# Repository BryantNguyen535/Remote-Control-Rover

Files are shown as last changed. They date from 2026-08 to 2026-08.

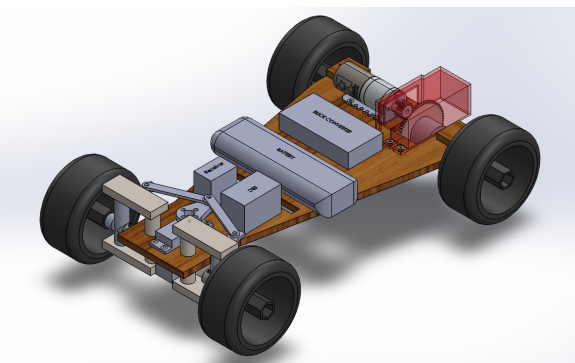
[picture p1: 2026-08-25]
Images/FinalAssembly.png

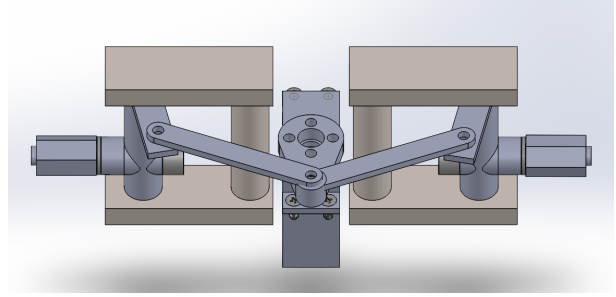
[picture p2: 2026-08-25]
Images/SteeringMechanism.png

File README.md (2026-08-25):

# Team Mott's RC Rover

A custom-designed remote-controlled rover built for **ENGR 7A: Introduction to Engineering** at the **University of California, Irvine (Fall 2023)**[cite: 2].

## System Overview

The Team Mott's Rover is an engineering prototype designed to traverse obstacles, navigate speed courses, and scale steep ramps[cite: 2]. The design features a custom Ackerman steering mechanism, high-torque gearing, custom wood chassis fabrication, and integrated safety covers[cite: 2].

## Key Specifications

| Specification | Value | Target Constraint |
| :--- | :--- | :--- |
| **Dimensions** | 13.94" L x 9.43" W[cite: 2] | < 16.0" L x 10.0" W[cite: 2] |
| **Vehicle Weight** | 1.20 kg[cite: 2] | Predicted: 1.39 kg[cite: 2] |
| **Total Build Cost** | $253.13 (incl. tax)[cite: 2] | < $275.00 limit[cite: 2] |
| **Power Source** | 7.2V 3600 mAh NiMH Battery[cite: 2] | ≥ 10 min operation[cite: 2] |
| **Drive Gear Ratio** | 4:1 (64T Spur / 16T Pinion)[cite: 2] | High-torque selection[cite: 2] |

---

## Subsystem Architecture

### Mechanical & Structural
* **Chassis:** Laser-cut 1/4" Baltic birch plywood featuring custom cutouts for central battery positioning and gear clearance[cite: 2].
* **Ackerman Steering:** Driven by a servo motor attached to a custom 3D-printed adapter horn that connects via rotating linkages to 2-inch D-shaft wheel pivots[cite: 2].
* **Drivetrain:** Features a 12V 4.4:1 metal gearmotor connected via a 64T spur gear to an 8-inch stainless steel rear D-shaft axle[cite: 2].
* **Wheels:** 85 mm rubber tires to maximize ground clearance over course obstacles[cite: 2].
* **Safety Integration:** Includes a transparent 3D-printed red gear guard covering moving drive teeth[cite: 2].

### Electrical & Controls
* **Power Distribution:** 7.2V 3600 mAh NiMH battery feeds directly to the Electronic Speed Controller (ESC) and Buck Converter[cite: 2].
* **Voltage Regulator:** 5A DC-DC Buck Converter steps down 7.2V input to a constant 5V output for the steering servo motor[cite: 2].
* **Radio Control:** 6-channel digital radio transmitter paired with a chassis-mounted receiver[cite: 2].

---

## Competition Performance

* **Preliminary Round:** Completed course in 26.75 seconds, ranking **8th out of 56 teams**[cite: 2].
* **Final Competition (Top 10):** Recorded a 36.00-second course run (+10s penalty for cone contact), securing **6th place overall**[cite: 2].

---

## Future Design Improvements

* **Steering Stabilization:** Replace glued joints with threaded M3 screw connections and shorten sleeve bearing hole depths to eliminate wheel wobble[cite: 2].
* **Friction Reduction:** Convert internal PLA-on-PLA linkage joints to M3 screw pivots[cite: 2].
* **Chassis Clearance:** Shorten overall chassis length or lower axle mount positions to clear ramp peaks without touching[cite: 2].

---

## Team Members

* **Alex M.** — Team Captain[cite: 2]
* **Brady C.** — Electronics Lead[cite: 2]
* **Bryant N.** — CAD Design Lead[cite: 2]
* **Christine R.** — Fabrication Lead[cite: 2]
* **Christine Y.** — Fabrication Lead[cite: 2]
* **Darcy M.** — Research Lead[cite: 2]
* **Emely B.** — Research Lead[cite: 2]

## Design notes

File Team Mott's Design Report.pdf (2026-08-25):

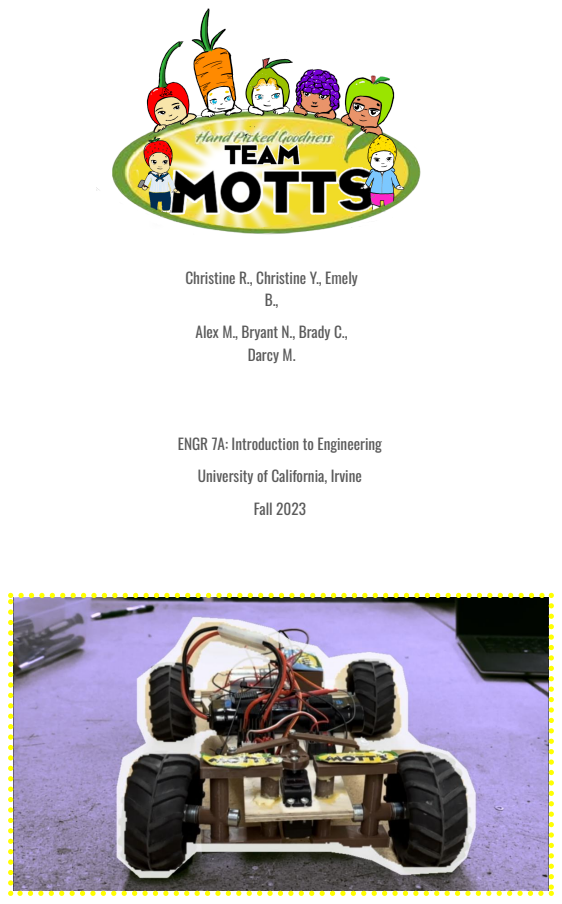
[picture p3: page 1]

Christine R., Christine Y., Emely

Alex M., Bryant N., Brady C.,
Darcy M.

ENGR 7A: Introduction to Engineering
University of California, Irvine
Fall 2023

## Table of Contents

# Executive Summary

ENGR 7A is the first portion of the two-quarter Introduction to Engineering course offered to UCI engineering Freshman. The main objective of this course is to teach its students the various processes and disciplines related to creating a remote control rover. Early on, the students were divided into various groups. Our group consisted of 7 individuals, all of different majors. We early on declared ourselves “Team Motts” when a group member decided to snack on the brand gummies during our first meeting. Few of us had experience with research design and manufacturing and even fewer had experience with electronics. As the course progressed, we would find ourselves dedicating much time building on these skills.
The project began with applying what we learned in lectures and labs onto our weekly action plans. Starting with the 3D CAD design modeling of the rover and its components on SolidWorks. Estimating our costs and collecting the information for the PO form. Then onto the safety protocols and procedures that go into the physical fabrication of the chassis and other smaller wooden parts. The soldering and positioning of the electronics soon followed. Lastly was the testing and evaluation of the end product. As a group, we met every Thursday from 2pm to 3 pm. Our assigned roles directed each of our contributions during and outside the meeting times.
Of course, throughout this whole process, there were many revisions and adjustments done to address issues we faced along the way.
Some of the issues included:
- Fabrication difficulties in original chassis design and steering design
- No space for wheel and motor compartments
- No way to mount rack
- Excessive friction

These issues were solved during labs and weekly meetings. New designs were made for the chassis and steering mechanisms, and different approaches were sought for any issues regarding positioning. Re-printing was also done for 3D components that were misprinted or had gone through revisions in order to fit into new designs.
For the most part, our rover took inspiration from the mechanisms of past accomplished rovers in the same course. Uniquely, our rover also took influence from the mechanisms of remote control toy cars.

Notably, the Ackerman steering system we used was quite different from most other teams as it incorporated rods and a 3D servo motor adapter.
Each member contributed their strengths towards the completion of a rover that not only followed the guidelines set upon us, but also exemplified the creativity of its members. The end product accomplished just that. The Team Mott’s rover is able to remotely be controlled to accelerate, reverse, turn, and climb over a ramp, all while proudly flaunting the Motts brand.

# Problem Definition

Introduction

Over the course of ten weeks, we were tasked with the assignment of fabricating a remotely controlled rover. Going into this project, we had general ideas of aspects desired in our rover such as a low center of gravity, speed, and high torque. Our holistic view of the rover developed as the weeks progressed. We were able to implement what we learned through labs and lectures into our designs, such as ackerman steering and a gear train. Designing and constructing a rover was something novel to the entire team, so the development of the rover was a learning process as well .

Technical Review / Background

The purpose of the rover was to traverse celestial bodies neighboring Earth, and to collect data and samples. In 1970, the Soviet Union developed the first ever rover which was designated the name Lunokhod 1. However, one the earliest records of a remotely controlled vehicle comes from a 1954 article, about a man by the name of David Swinder, which showcases his remote controlled vehicle to the chief test driver of Ford. Rovers have come a long way from Lunokhod 1, with many having developed more specific tasks than just to curiously explore extraterrestrial planes. For example, the most recent rover launched was ‘Perseverance’ by NASA is currently journeying across Mars to look for “signs of past life”, as well as for the ability for humans to live on Mars.
In total transparency, our designs were primarily influenced by what we learned in lab and lecture, but cemented through further research. Designs such as the ackerman steering, gear ratio, materials and center of mass were instructed to us in lecture, which were implemented into our rover as a result.

Resources:

Howell, E. (2016, December 20). Lunokhod 1: 1st successful Lunar Rover. Space.com. https://www.space.com/35090-lunokhod-1.html

RCModels 1954 Ford Motor Company Concept. Thirteen point seven billion. (n.d.). https://palmeter.com/rcmodels-1954-ford-motor-company-concept/

Urbain, T. (2023, May 14). How many Rovers & Landers are currently on Mars?. StarLust. https://starlust.org/how-many-rovers-are-on-mars/

What makes a Rover? - chabot space and science center. (n.d.). https://chabotspace.org/wp-content/uploads/2020/04/What-Makes-a-Rover-1.pdf Design Requirements

Size requirements:
(a) Overall width must be smaller than 10 inches.
(b) Overall length must be smaller than 16 inches.

Structure requirements
(a) Your team will design and fabricate the rover structure.
(b) Using an off the shelf chassis is not allowed.
(c) Off the shelf steering mechanisms or individual linkage components are not allowed.
(d) You are allowed to use raw materials purchased externally with the permission of your TA or technical staff.
(e) 3D printing of the steering mechanism and any associated attachments is allowed, but must be counted toward your budget.

Power and propulsion requirements
(a) The use of internal combustion engines (gas and glow fuel engines) is prohibited.
(b) Rover must be able to operate for at least 10 minutes without replenishing/recharging its energy source.
(c) On/off switch is required and must be easily accessible.
(d) Battery must be easily removable.

Safety requirements
(a) Must include a gear guard to protect against any contact with the gears when in motion.
(b) No protruding sharp objects. All sharp corners must be filed or sanded down.
(c) All wires must be neat and away from any moving parts. This includes, rotating axles, motor shafts, servos, linkages, and gears.
(d) All wires and connectors are to be completely covered and insulated.

Cost requirements
(a) Total as-built replacement cost of the rover must be less than $250 If you decide to incorporate 3-D printing, the budget must be less than $275.
(b) The cost must be broken down into a Bill of Materials (BOM)/Parts List, in which the Fair Market Value (FMV) of each component must be listed.

Product Deliverables
(a) The RC rover
(b) Final design report
(c) The final Bill of Materials/Parts List
(d) Preliminary and final Gantt charts
(e) All design drawings and schematics
(f) The oral presentation (PowerPoint slide file)

# Design Description

Summary of Design

The final design of our rover is pictured to the right. It includes the steering system, the drive train, and the electronics all connected by a wooden chassis. The steering system is at the front of the rover. It controls the direction that the front wheels are pointing by turning a servo motor. The drivetrain is in the back and
controls the direction and the speed of the
back wheels.

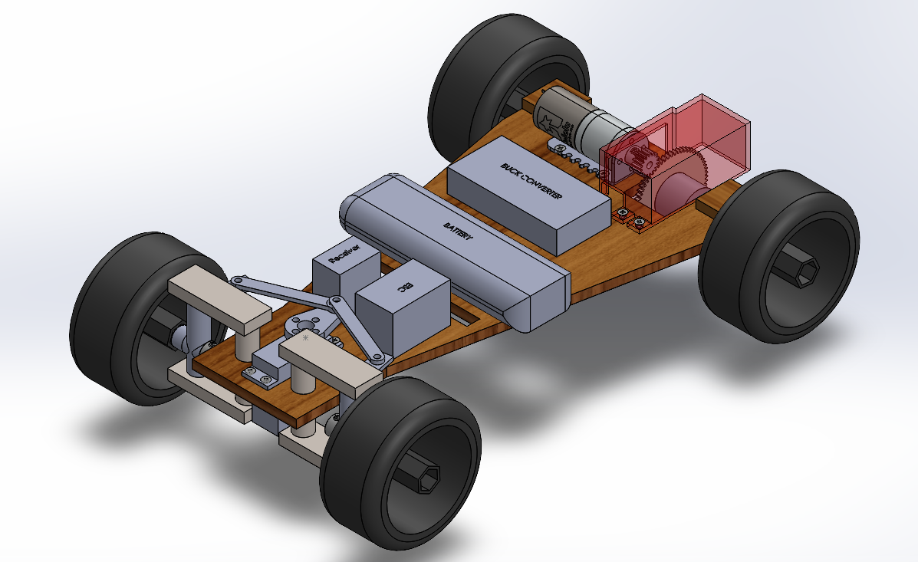
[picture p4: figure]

The gray parts in the middle of the steering system and rear axle are the electronics. The battery is placed in the middle because it is the heaviest part. This keeps the center of gravity close to the middle of the rover, lowering the chances of the rover tipping over or being unstable. The battery is attached to the chassis via velcro straps that go through holes cutout in the chassis. The buck converter is attached to the chassis with 2 M3 screws. The other electronics, including the ESC, On/Off switch, and receiver are attached to the chassis with double sided tape. Each of the parts are strategically placed to be near the other parts that they are plugged into. This keeps the wires neat in the final design.

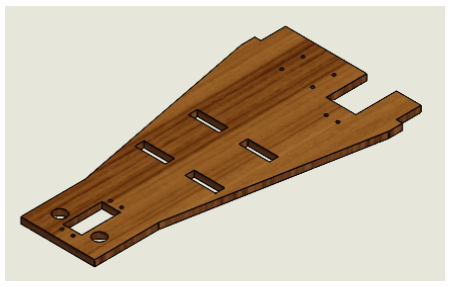
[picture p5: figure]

We chose to use 85 mm wheels, as they were the largest available wheels for this project. The large wheels made traversing rough terrain and driving over the peak of the ramp easier. The overall dimensions for the entire rover came out to be 13.94 inches by 9.43 inches, which fits the requirements that the size needs to be within 16 inches by 10 inches.

Design Details

For the steering system, we decided to 3D print the majority of the parts. The servo motor is attached to the chassis with 4 M3 screws, and goes through a hole in the chassis to hold it lower. Connected to the servo horn is a
3D-printed adaptor (pictured below)
that screws into the servo horn and

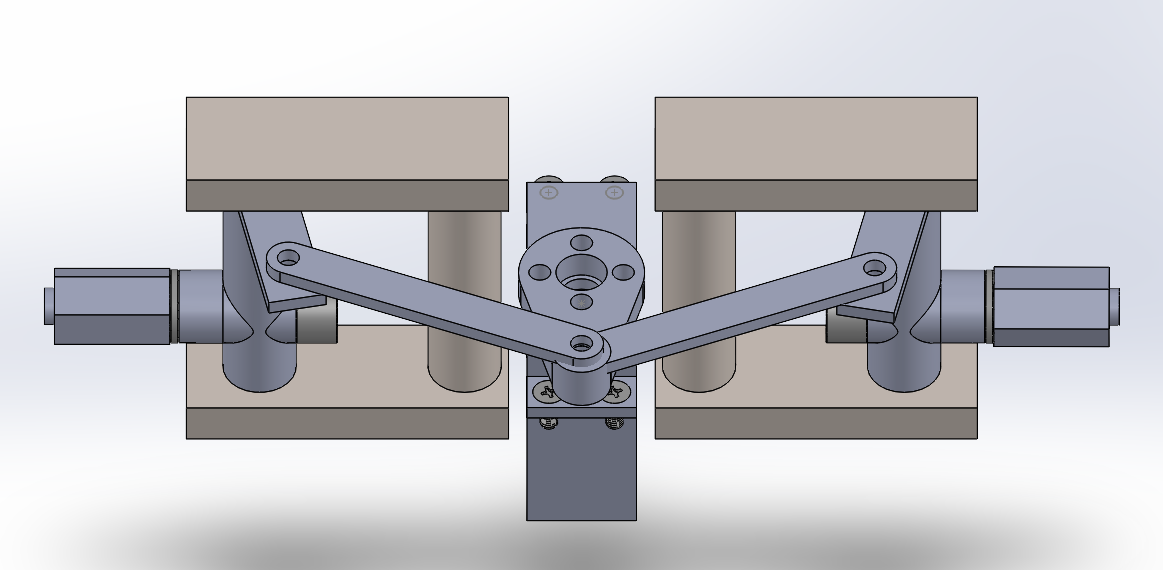
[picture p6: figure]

attaches to two rotating rods on the other end. This piece holds the rods farther away from the axis of rotation, therefore compounding the amount of linear motion when the servo rotates. Those two
rods are each connected with M3 screws to a
rotating part that holds the 2-inch D shafts, which connect to the wheels. These rotating parts are held up by connectors (tan pieces) that allow them to rotate and secure them to the chassis. In total, including the wheels, the width of the steering system is 9.4 inches, which is within the maximum of 10 inches.

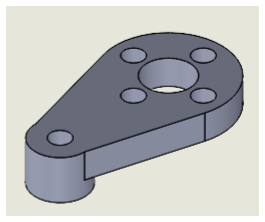
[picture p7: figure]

The drive train of our rover is in the back. This system is quite simple in that it just secures the 8-inch D shaft to the chassis and connects it via a gear train to the motor. The D shaft is held up using wooden cutouts. They are glued to the chassis, and have
other wooden cutouts glued on top of them to
reinforce them. This is because these connections
hold up the weight of the rover. The D shaft is below the chassis to raise the rover as high as possible. This raises the center of gravity, but it allows the
rover to go over the ramp on the obstacle course. There is a cutout in the wooden chassis to allow the

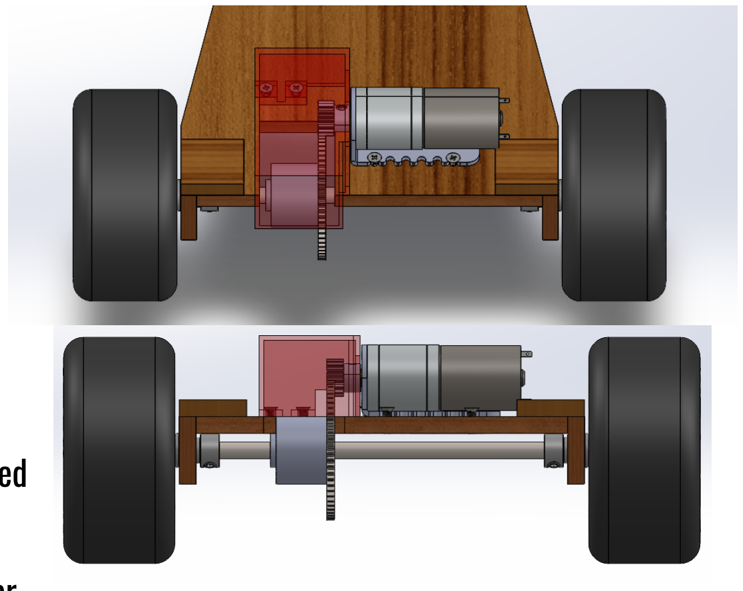
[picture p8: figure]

gear to spin and connect to the motor, which is screwed into the chassis using the motor mount. The transparent red piece in the image is a 3D printed gear guard that connects to the chassis with M3 screws. The gear guard is put over the gear to protect any foreign objects from interfering with the gear and the motor.

Wiring Diagram

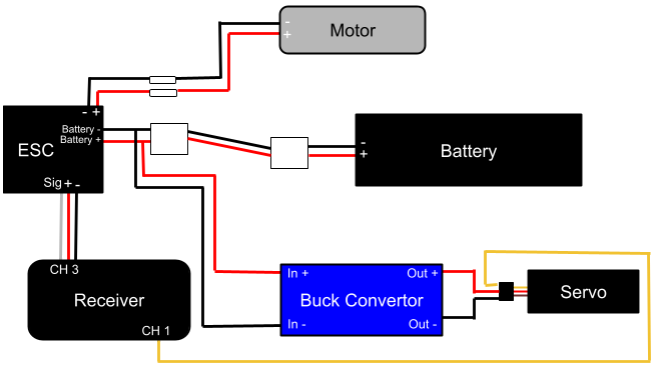
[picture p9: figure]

The above image is a computer-generated diagram of the entire wiring network. All wires are color coded; red representing the positive charge and black representing the negative charge. We incorporated the following electronics: servomotor, Electronic Speed Controller (ESC), battery, buck convertor, motor, and a receiver. We powered the ESC and the buck converter with a 3600 mAh battery. The ESC controls the speed of the motor. The buck converter steps down the 7.2 V from the battery to a constant 5 V, and feeds this into the servo motor. The receiver is connected to both the servo motor as well as the ESC. This takes input from the transmitter and controller both the servo and the motor allowing us to remotely control the rover.

# Action Item Report

Task Assignment

Each week during the quarter (besides Week 1), we met on Thursday from 2-3pm at the most convenient and appropriate location. In Week 2, each member of the team was assigned a role as listed below.

- Team Captain: Alex
- Electronics: Brady
- CAD Design: Bryant
- Research: Darcy, Emely
- Fabrication: Christine R,. Christine Y.

We treated the team member who was in charge of each respective job as the leader in getting their job done. For example, if Bryant needed help completing the CAD Design, it was his job to delegate the tasks to other team members. This way, although everyone was assigned one job, everyone had an opportunity to partake in every task.

The following is the Action Item Report for each week:

- Week 2:
- Assigned Roles (Team Captain, Electronics, CAD Design, Research, Fabrication)
- Created Team Name
■ Named after Mott’s fruit snacks!
- Began researching rover designs and steering systems
- Week 3:
- Created Gantt Chart
- Designed Chassis in SDW
- Continued researching steering systems

- Week 4:
- Redesigned Chassis
■ Our first chassis design was deemed too hard to replicate by the TA’s
- Designed Steering System
- Decided on Gear Ratio
■ 64T
- Designed Rear Axle System
- Created PO Form
- Week 5:
- Redesigned Steering System
■ Originally Rack and pinion. Reasons included being too hard to replicate and its specifications
■ Our new steering system is much easier to fabricate and fits the steering mechanism
- Began brainstorming Extra Credit Video
■ Timelapse of work progress
- PO Form: Due November 3
- Week 6:
- Created Gear Guard
- Finalized SDW Design
- Put all parts into CAD assembly
- Final Solidworks design: due November 10
- Week 7:
- Fabricated Chassis
■ Setback: our chassis blew up and we had to re-fabricate another chassis
- Fabricated Rear Axle System
- Preliminary presentation slides: due November 17

- Week 8:
- Fabricated Steering System
- Signed up for open lab days
■ Assembled Electronics
■ Tested Electronics
- Rover: turned in on November 22
- Week 9:
- Tested Rover
- Adjusted Steering System
- Week 10:
- Competitions (12/6 @ 1pm, 12/7 @ 3pm) ■ First round: 8th place
■ Second round (top 10 round): 6th place
- Finals Week
- Final presentation, video, and design report due on day of presentation (12/11 @ 4pm)

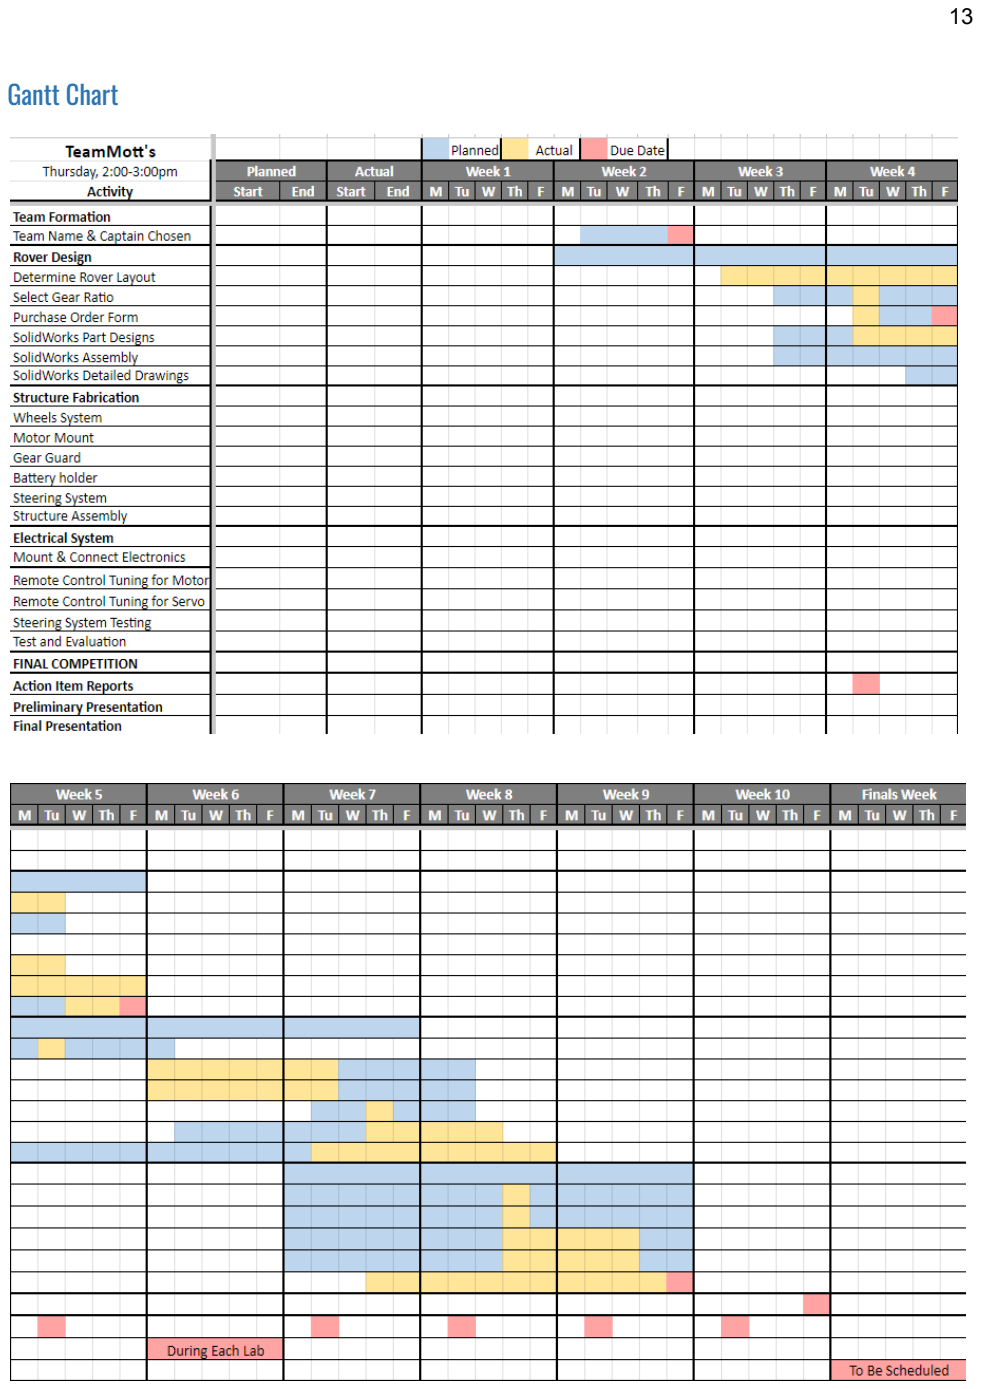
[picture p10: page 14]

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
# Evaluation

Calculations

Estimated Weight of Vehicle:

Weigℎt ≈ Σ(W
Eacℎ component

) = W
Battery

+ W

Cℎassis + W

ESC + W

Motor + W

Servo + W

Buck Converter +...

... + W

Wℎeels + W

D−Sℎafts+ W
3D Printing

Weigℎt ≈ 0. 367 Kg + 0. 2 Kg + 0. 1 Kg + 0. 082 Kg + 0. 22 Kg + 0. 016 Kg + 0. 17 Kg +... ... + 0. 072 Kg + 0. 1Kg = 1.39 Kg

The actual weight of the Rover is 1.2 Kg, which is 0.19 Kg less than our estimated weight. This is likely due to inaccuracies in the listed weights for each part and rounding.

Predicted drive time:

DC Motor Stall Current =

(Battery Voltage)

(12V/5A) | = 7.2V
| (12V/5A) = 3A

Servo Stall Current = 3A

Drive Time = | 36 Minutes
(Battery Capacity)
(DC Motor Stall Current)+(Servo Stall Current) =
| 3.6Aℎ
| 3A+3A = 0. 6 Hours =

Gear Ratio:

There were 3 options for the gear: 40T, 52T, and 64T. The higher the gear ratio, the higher the torque, but the lower the speed. The torque and the speed can be found using the following formula where N2

is the
number of teeth on the output gear and N1

is the number of teeth on the input gear.

Mecℎanical Advantage =

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
Using this formula, the Torque and the Speed for each gear is listed below. Also, the Stall Mass can be experimentally measured by finding the lowest mass that the motor cannot lift using each gear. It is also listed below.

- 40T:
- Torque = 0.2895 Nm
- Speed = 0.4 ωMotor
- Stall Mass = 1.672 Kg
- 52T:
- Torque = 0.3716 Nm
- Speed = 0.308 ωMotor
- Stall Mass = 1.967 Kg
- 64T:
- Torque = 0.4574 Nm
- Speed = 0.25 ωMotor
- Stall Mass = 2.756 Kg

Since the exact mass was unknown at the time, and the speed loss using the 64T gear was not too significant (0.25 times the input speed instead of a max of 0.4 times the input speed), we chose to use the 64T gear. This choice valued torque and therefore controllability over speed. Another reason for this choice was that, while moving up the ramp on the course, the rover would need a higher torque in order to not stall and be unable to drive up the ramp.

Turning Radius:

Turn Radius = | 17.53 cm
Wℎeelbase
tan(angle) =

27 cm
tan(57 degrees) =

Test Plan

The Rear axle system, which includes the motor, gear guard, and rear wheels, was tested throughout the design process. We first combined all the parts in a Solidworks Assembly, and created mates so the system would interact as it would after fabrication. We moved the axle below the chassis to raise the rover and to make it easier to pass over obstacles. After we were satisfied that the system was working properly, we added sleeve bearings and shaft collars to the assembly. The system was then fabricated and assembled. We glued an extra piece of wood to the chassis to strengthen the bond from the rear axle mount to the chassis, and we loosened the fit of the sleeve bearings to allow the D-Shaft to rotate with less friction. After we were satisfied that the system was working properly, we did our full integration test.
The Steering System was tested in a similar way. We first made our design on Solidworks and used mates to create the assembly. We made sure that the wheels moved as predicted when moving only the servo horn. We made adjustments to minimize material and optimize the turn radius. We also ensured that the 2 inch D-Shaft, sleeve bearings, and shaft collars could fit, and we changed connections from PLA on PLA to M3 Screws. We also ensured that the model was less than 10 inches wide so the rover would follow the guidelines. After we were satisfied with the CAD, we fabricated the steering system. To test it, we first held it off the ground to make sure nothing would break while we first tested the turning. We determined that we needed a smaller turn radius, so we redesigned the servo adapter to be longer. The servo adapter also snapped when driving over the cones, and there were screws that stopped the system from using its full range of motion, so we redesigned one to be stronger and better fitted to the design. When we tested the rover, we noticed that the turn radius when turning right was too large because the rod was hitting a screw on the servo horn. To fix this we moved the screws to only the holes opposite from that rod.
The testing of the electrical system was quick. We connected all the parts (while not connected to the chassis) according to the wiring diagram. After adjusting the buck converter voltage and ensuring the servo and motor operated as planned, we attached all the parts to the Chassis. We then did a full integration test with no problems.

Results & Discussion

Overall, the rover performs well. Our rover ran the course in 26.75 seconds, which is 8th fastest out of 56 teams. Because we were top 10, we competed in the final competition on a harder course. We finished with a time of 36 seconds plus a 10 second penalty for hitting a cone. This awarded us 6th in the competition. Our rover fits all the requirements, and it is stable and relatively lightweight. The rover drives at a fast speed, but not too fast that it is uncontrollable, so the choice of gear ratio was good. The rear axle system is very stable and durable. It does its job perfectly, and there is very little that we would do to the system to make it better. However, if we were going to make another rover, there are some things we would change.
First, the steering system has a few concerns. The connection from the steering system to the 2 inch D-Shafts are a little unstable and wobbly. This is because the hole for the sleeve bearing is the same diameter all the way through, and does not take into account the length of the sleeve bearing. For this reason, the 3D printed connection could break under a stronger weight. To fix this problem, we could make the hole shorter, so it is just the length of the sleeve bearing. This would reduce the torque on the plastic and reduce the shaft’s ability to wobble.
Also, one of the rotating parts in the steering system is PLA on PLA. This creates more friction than if the connection was just an M3 screw. The simple fix is to make the steering system shorter, so all the connections can be M3 screws.
Another problem is that the connection from the wheel mount to the chassis is made with glue. This means that the connection is not as strong as it could be, and it is difficult to take apart if changes need to be made. It also made fabrication difficult, causing the parts to be not completely straight. Additionally, because this connection was made with glue, it came loose after a lot of testing, meaning we had to re-glue it. We ended up having to attach an extra piece of wood to make the connection more sturdy. With all of these considerations in mind, the steering system would need a redesign to have all M3 screw connections, bigger, more durable parts, and stronger, less wobbly connections to the D-Shafts.
The last change we would make is to make the chassis shorter. We overestimated how much space the electrical components would take, so we had room to shorten the chassis. Our rover can go over the ramp obstacle on the course, but it touches the top, so it could get stuck if it does not have enough speed. If we shortened the chassis or lowered the rear wheels, it would go over the ramp much easier.

# Appendix A: SOLIDWORKS Drawings

Final design drawings, individual parts, and full assembly, updated from Week 5 submission.

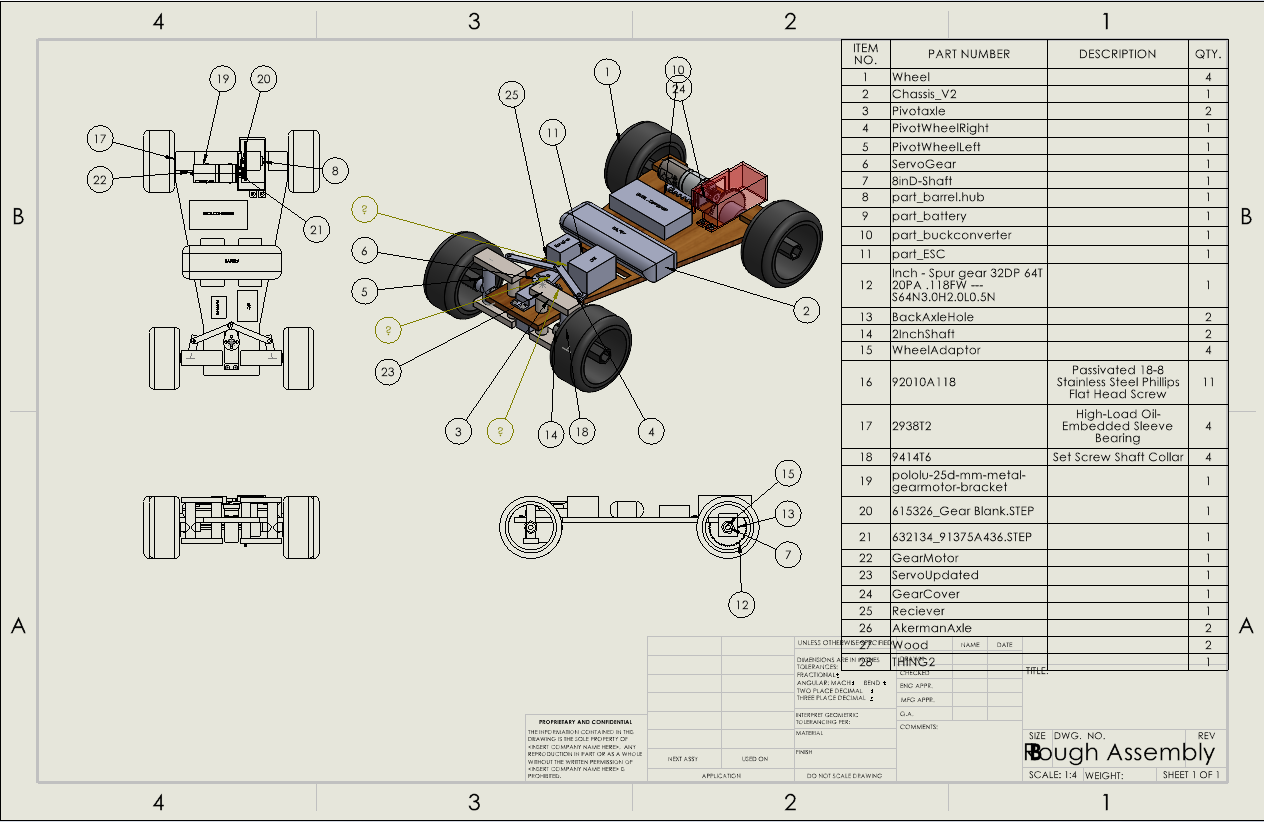
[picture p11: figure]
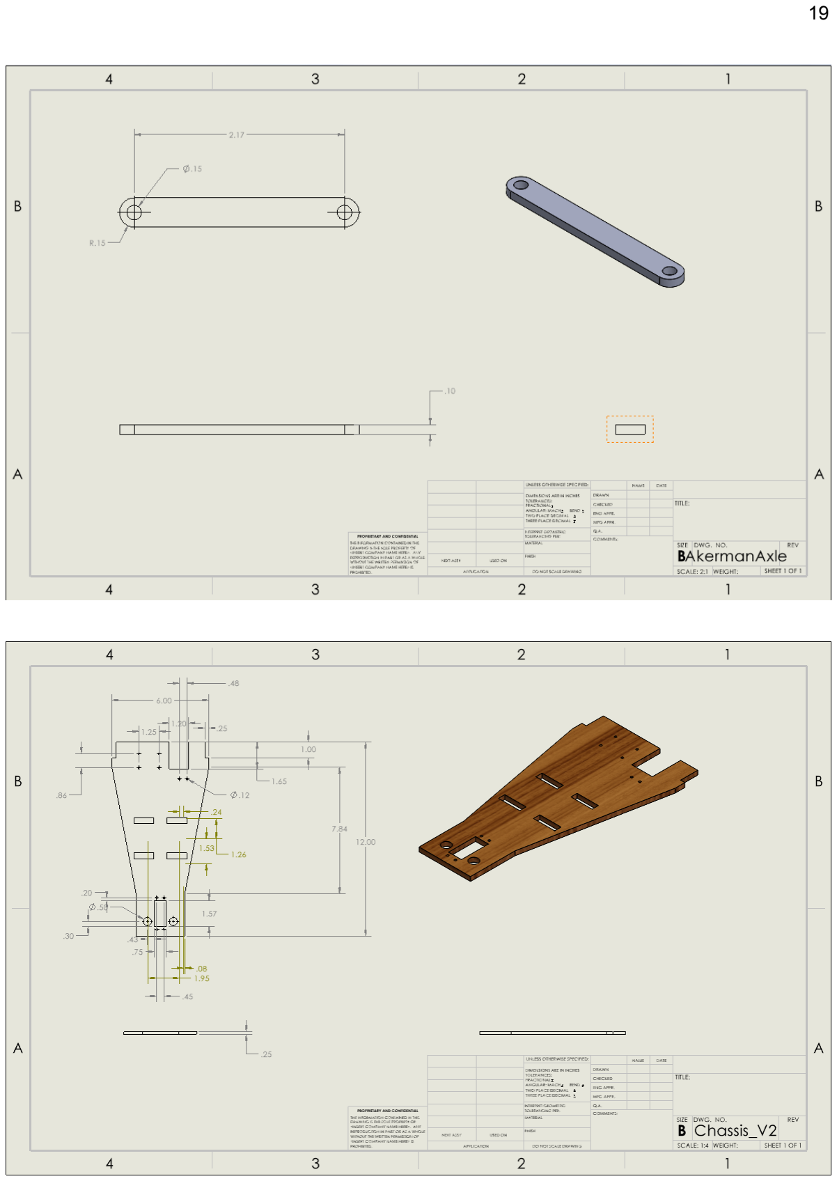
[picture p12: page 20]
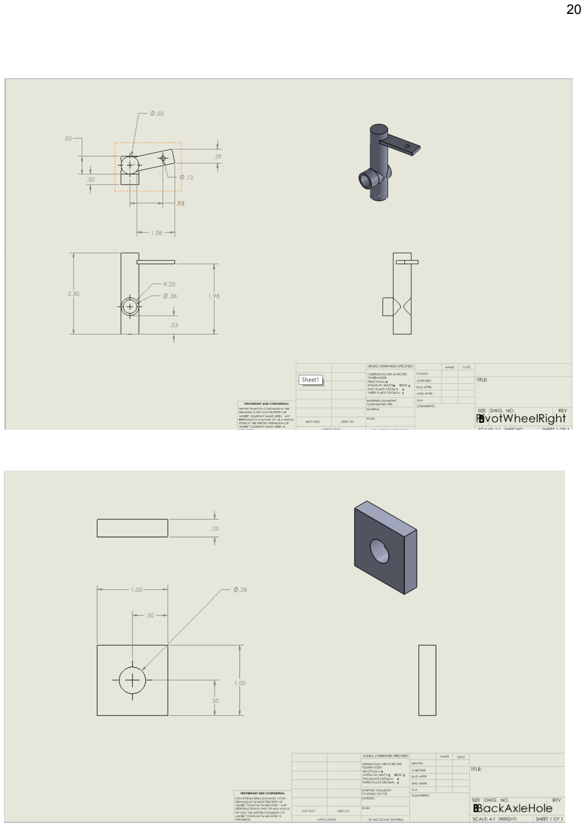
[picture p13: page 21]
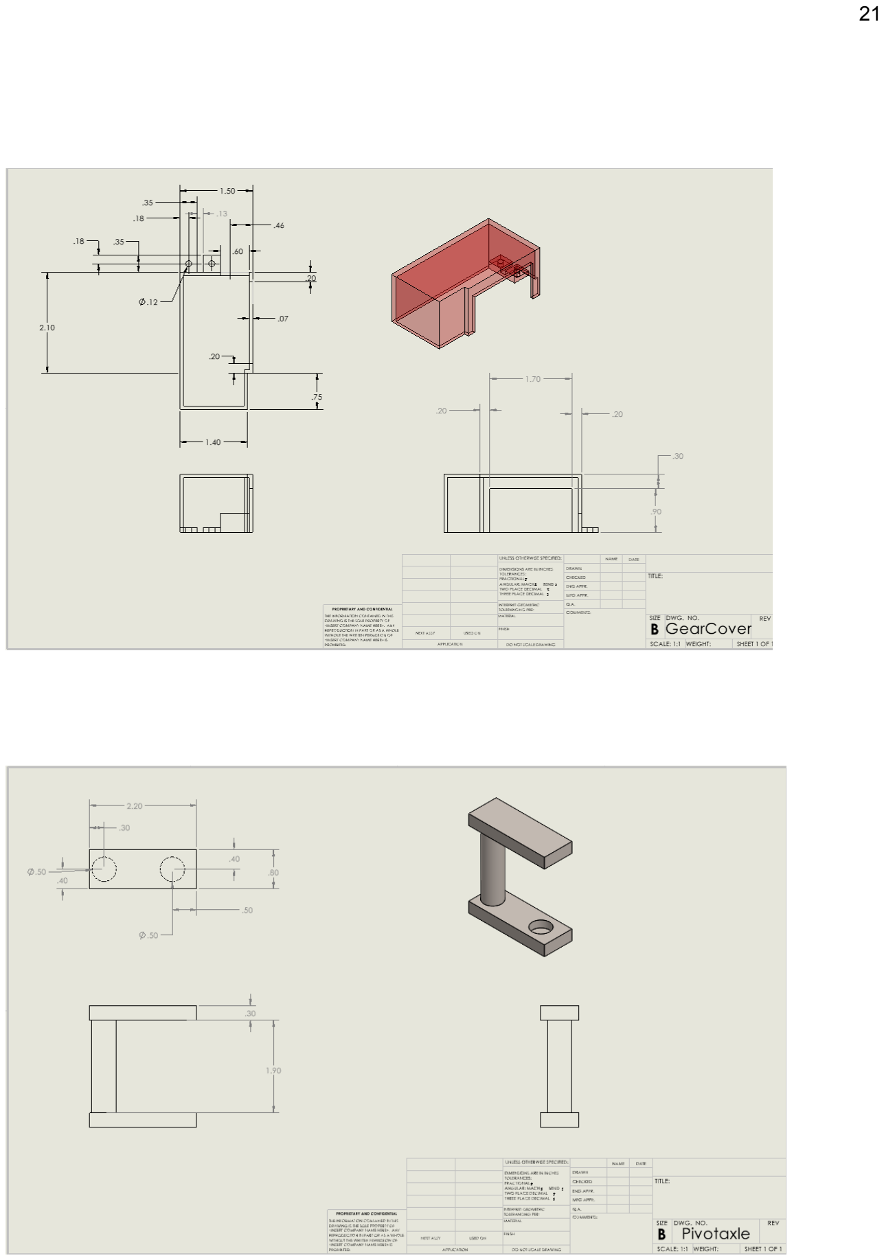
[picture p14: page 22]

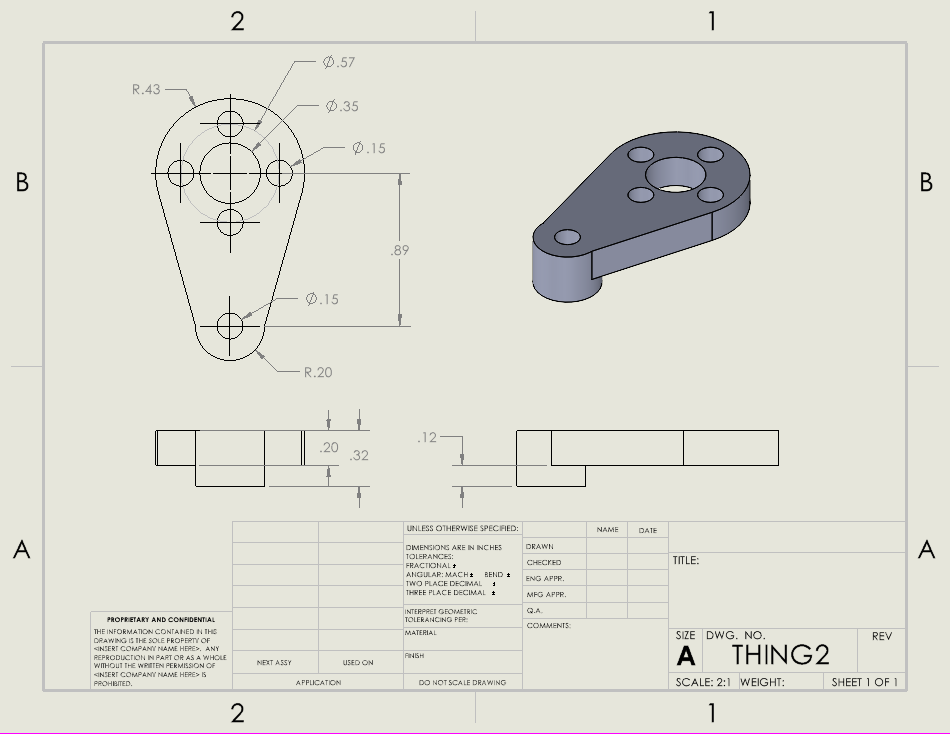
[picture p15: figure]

# Appendix B: Bill of Materials

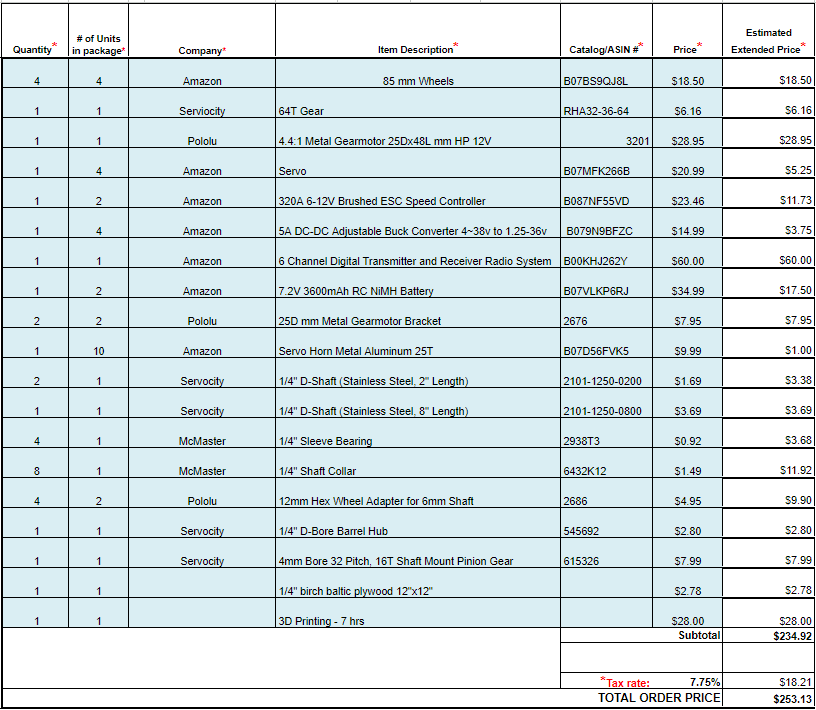
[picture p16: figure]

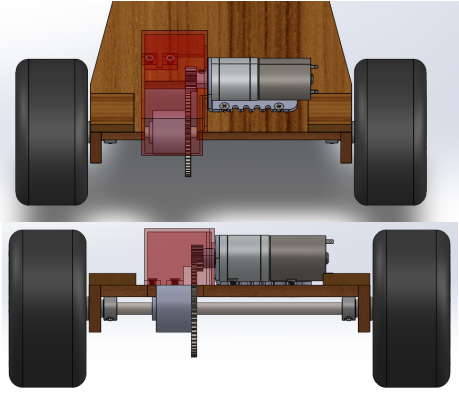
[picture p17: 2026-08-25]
Images/DriveMotor.png

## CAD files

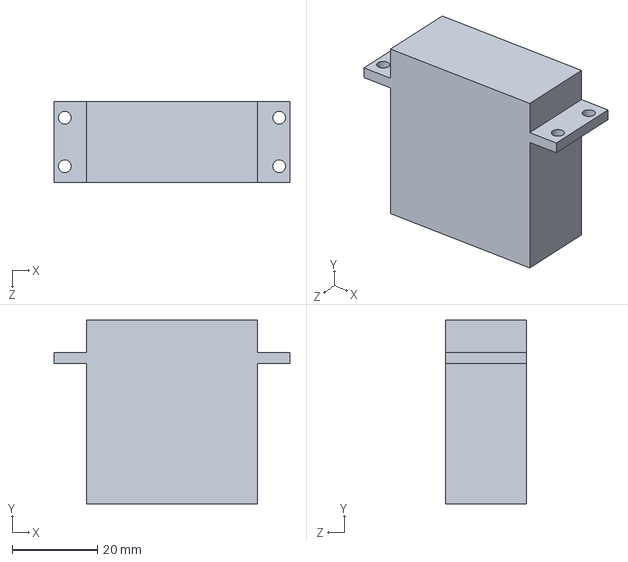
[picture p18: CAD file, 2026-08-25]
CAD files/ServoUpdated.SLDPRT
55.2 x 43.0 x 19.0 mm

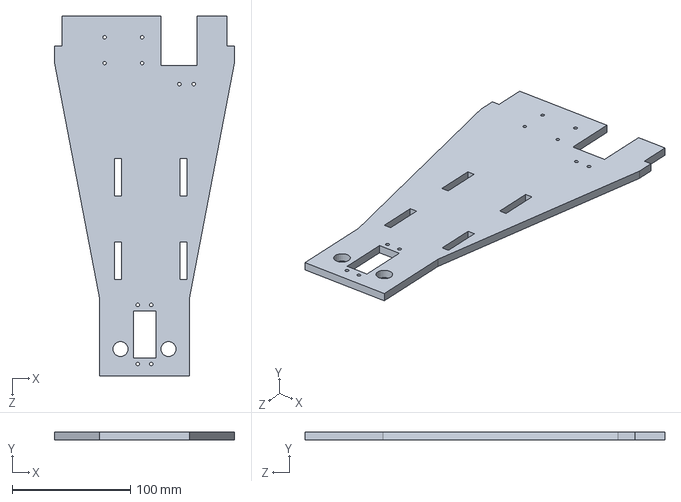
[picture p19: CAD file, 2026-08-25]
CAD files/Chassis_V2.SLDPRT
152.4 x 6.35 x 304.8 mm

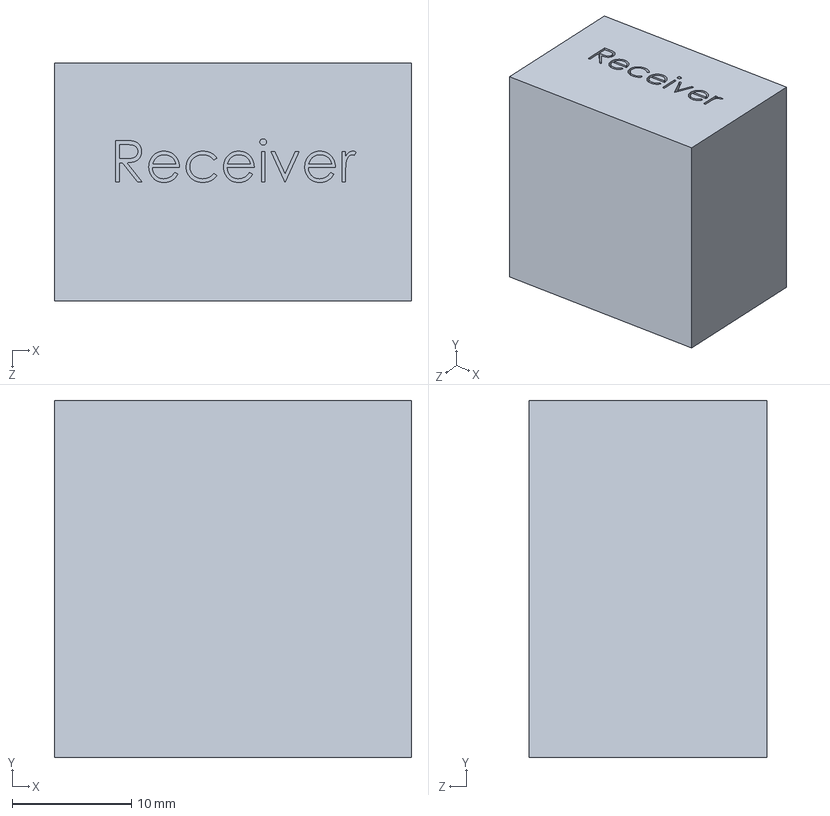
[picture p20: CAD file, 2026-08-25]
CAD files/Reciever.SLDPRT
30.0 x 30.0 x 20.0 mm

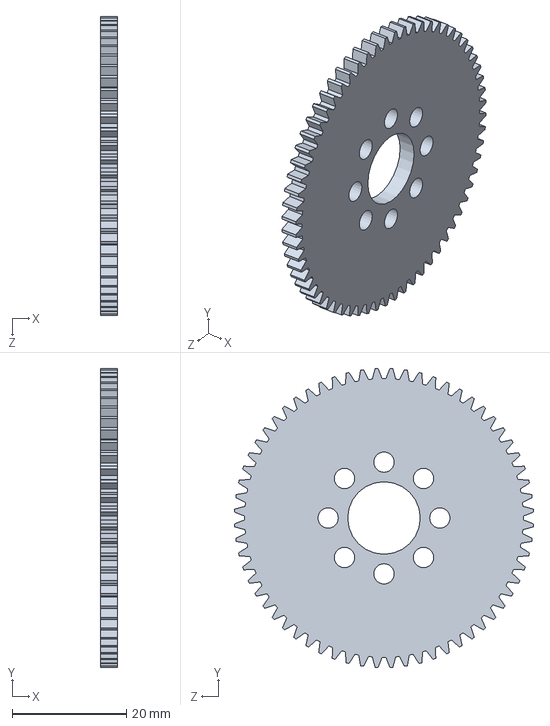
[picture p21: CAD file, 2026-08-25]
CAD files/64TGear_V3.SLDPRT
3.00 x 52.3 x 52.3 mm

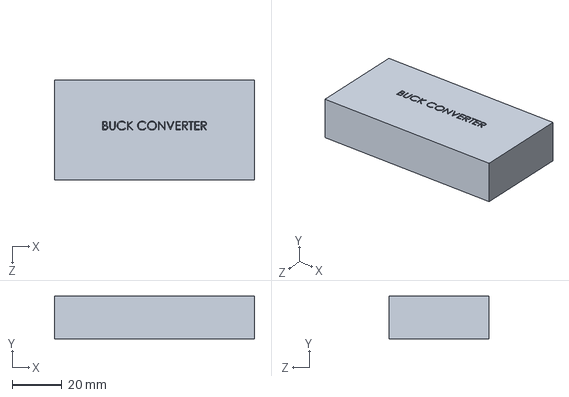
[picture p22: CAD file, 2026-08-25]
CAD files/part_buckconverter.SLDPRT
80.0 x 17.0 x 39.9 mm

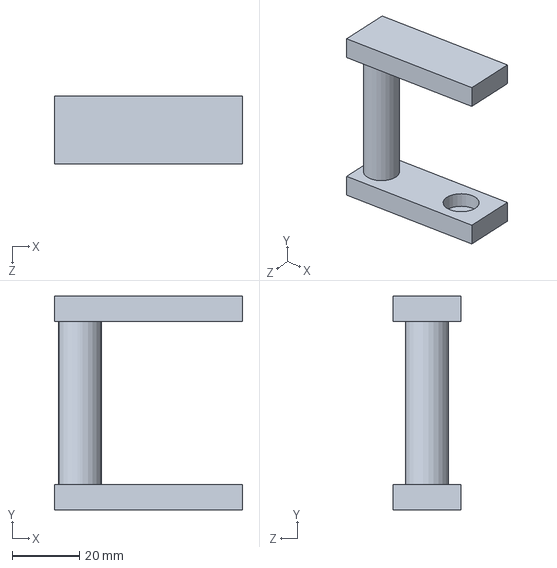
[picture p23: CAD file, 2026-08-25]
CAD files/Pivotaxle.SLDPRT
55.9 x 63.5 x 20.3 mm

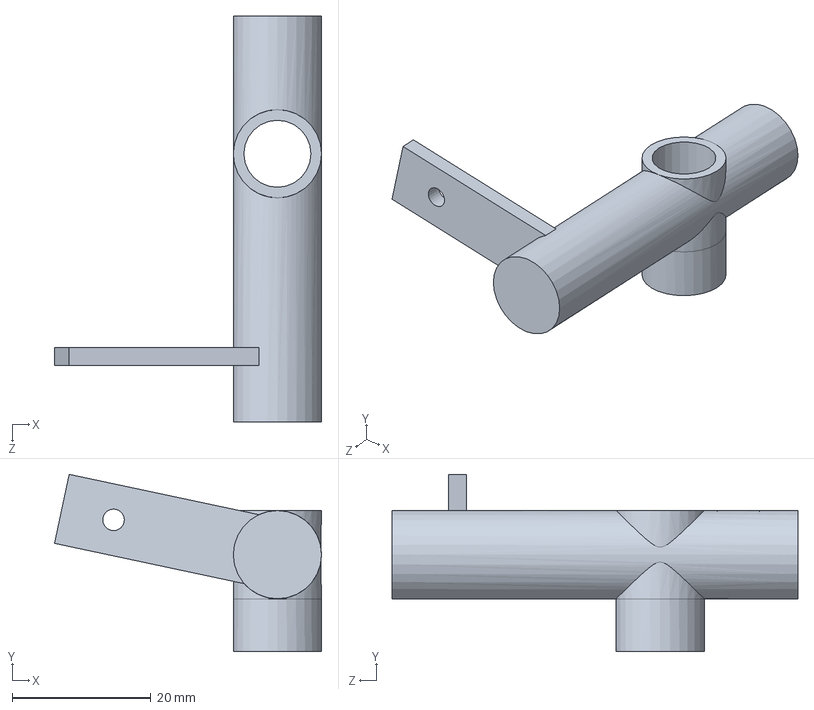
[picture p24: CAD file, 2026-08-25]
CAD files/PivotWheelLeft.SLDPRT
38.5 x 25.5 x 58.4 mm

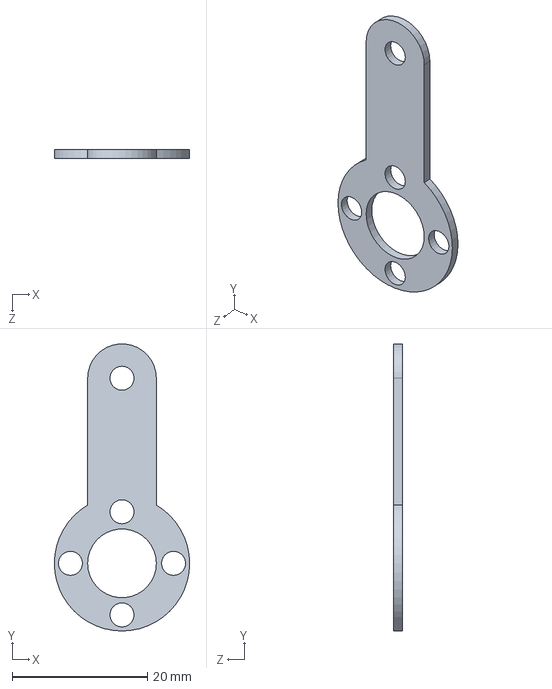
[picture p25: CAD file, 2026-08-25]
CAD files/THING.SLDPRT
20.0 x 42.4 x 1.27 mm

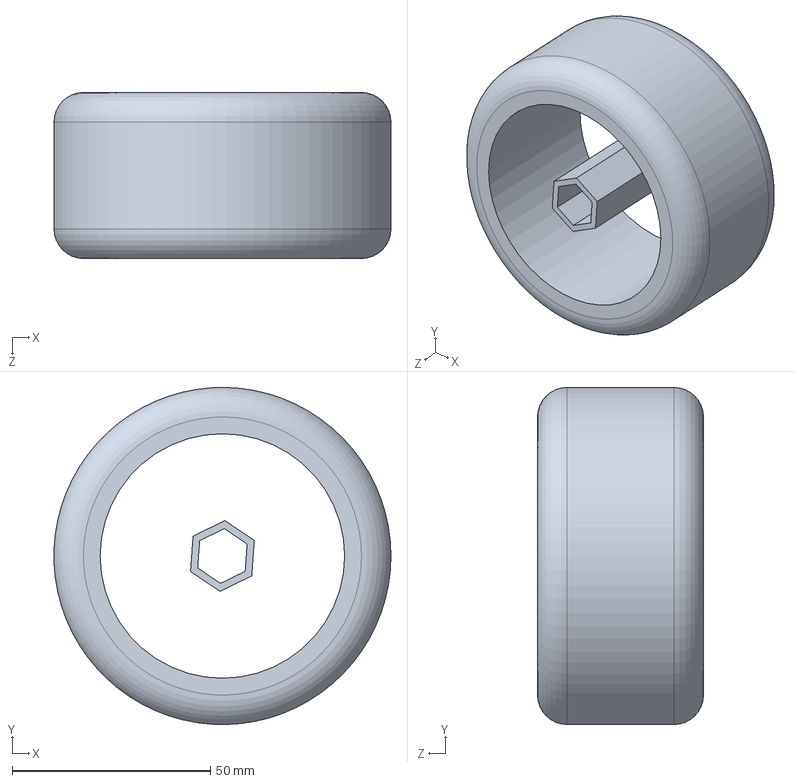
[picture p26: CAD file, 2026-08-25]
CAD files/Wheel.SLDPRT
85.1 x 85.1 x 41.9 mm

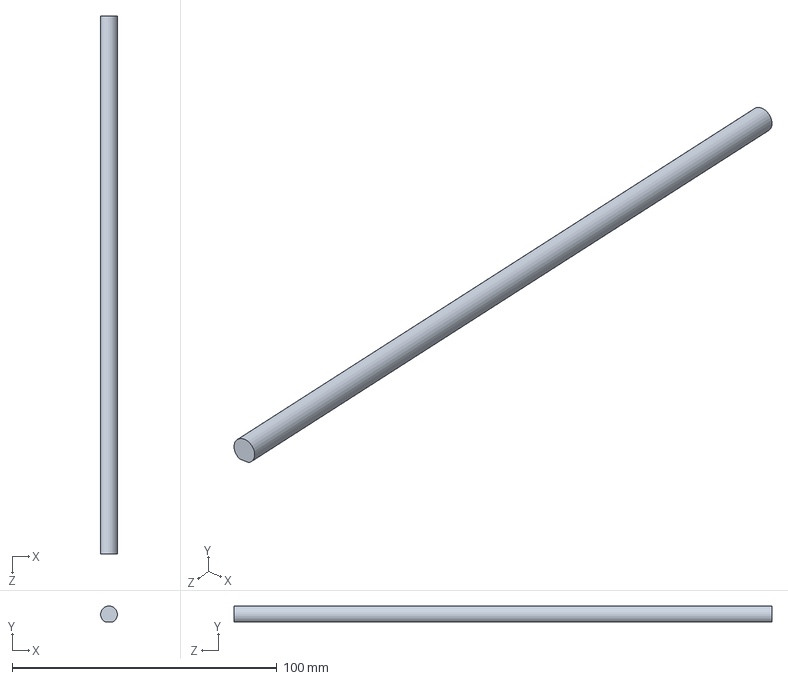
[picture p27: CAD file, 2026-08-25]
CAD files/8inD-Shaft.SLDPRT
6.34 x 6.01 x 203.2 mm

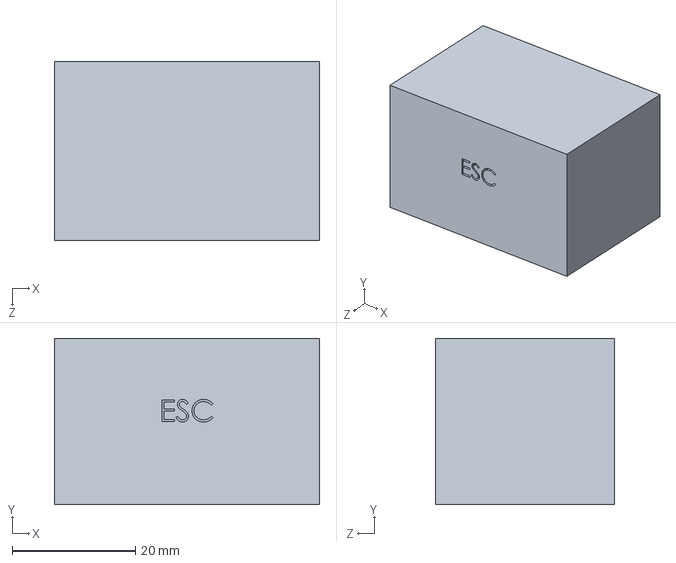
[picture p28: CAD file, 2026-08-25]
CAD files/part_ESC.SLDPRT
43.0 x 27.0 x 29.0 mm

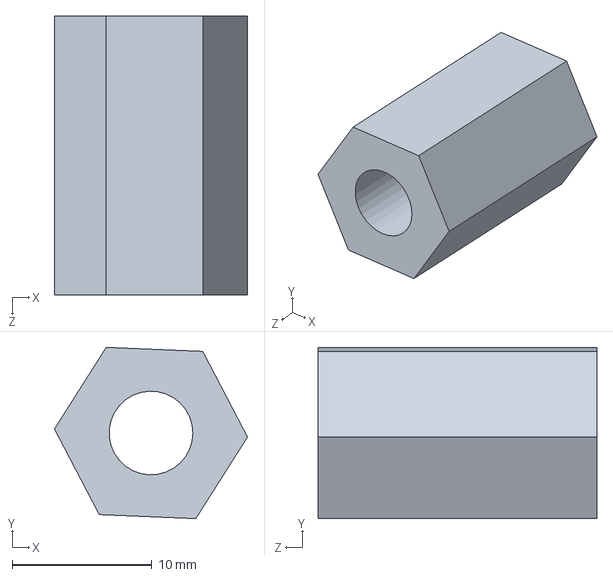
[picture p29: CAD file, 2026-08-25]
CAD files/WheelAdaptor.SLDPRT
13.8 x 12.3 x 20.0 mm

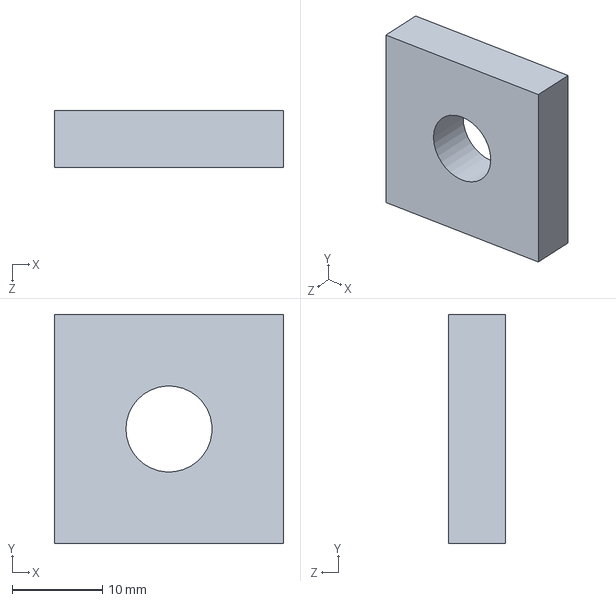
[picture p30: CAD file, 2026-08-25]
CAD files/BackAxleHole.SLDPRT
25.4 x 25.4 x 6.35 mm

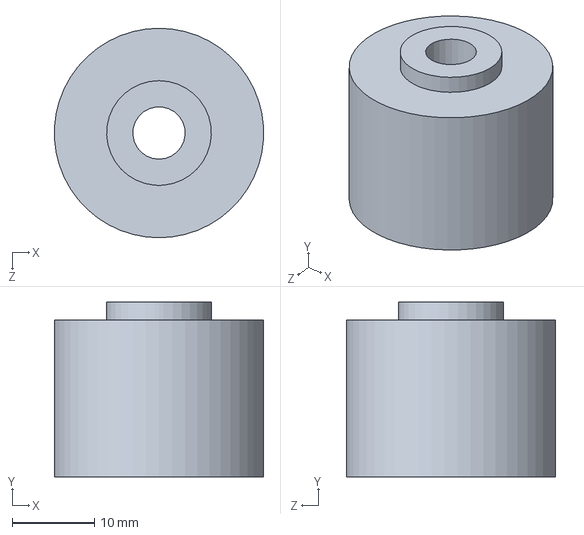
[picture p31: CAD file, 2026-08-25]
CAD files/part_barrel.hub.SLDPRT
25.3 x 21.2 x 25.4 mm

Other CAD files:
CAD files/Rough Assembly.SLDASM
CAD files/PinionGear assembly.SLDASM
CAD files/PivotWheelRight.SLDPRT
CAD files/GearCover.SLDPRT
CAD files/2938T2_High-Load Oil-Embedded Sleeve Bearing.SLDPRT
CAD files/2InchShaft.SLDPRT
CAD files/92010A118_Passivated 18-8 Stainless Steel Phillips Flat Head Screw.SLDPRT
CAD files/9414T6_Set Screw Shaft Collar.SLDPRT
CAD files/AkermanAxle.SLDPRT
CAD files/GearMotor.SLDPRT
CAD files/Servo.SLDPRT
CAD files/ServoGear.SLDPRT
CAD files/ShaftCollar.SLDPRT
CAD files/part_battery.SLDPRT
CAD files/pololu-25d-mm-metal-gearmotor-bracket.SLDPRT
